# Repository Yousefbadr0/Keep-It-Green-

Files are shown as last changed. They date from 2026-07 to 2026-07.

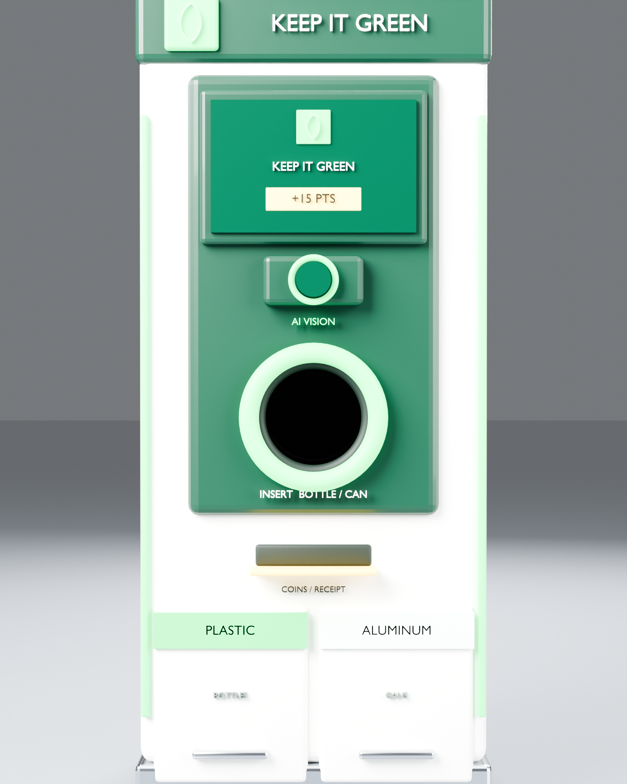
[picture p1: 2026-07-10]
Design/renders/keep_it_green_front.png

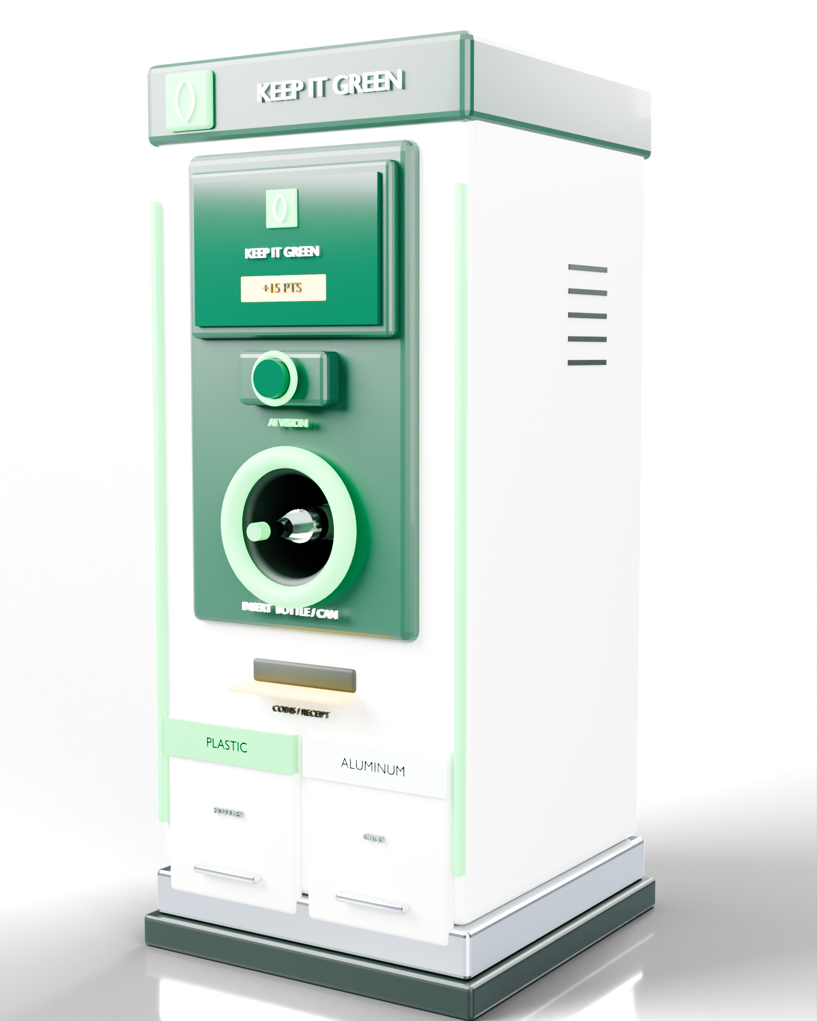
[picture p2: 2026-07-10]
Design/renders/keep_it_green_cutout.png

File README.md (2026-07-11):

# Keep It Green 🌱

An AI-powered smart recycling reward system — graduation project, Menoufia University,
Faculty of Electronic Engineering, Dept. of Computer Science & Engineering (2024–2025).

A user pairs their phone with a recycling machine (ATM-style QR / 6-digit code), inserts
plastic bottles or aluminium cans, a YOLOv8 detector recognizes the material, an Arduino
opens the right compartment, and reward points land on the user's account instantly.

**Live demo:** https://keepitgreen.runasp.net (web app + kiosk + Swagger API docs)

## Repository map

| Folder | What it is | Tech |
|---|---|---|
| `Recycle/` | Backend REST API + web app + kiosk UI (served from `wwwroot/`) | ASP.NET Core (.NET 10), EF Core, SQL Server, JWT |
| `Mobile/` | User + admin mobile app | Flutter (Dart), Material 3 |
| `AI/` | The machine: detector + kiosk driver + Arduino | Python, Ultralytics YOLOv8, pywebview, pyserial |
| `AI/recycling_machine/` | Arduino Nano sketch (2× SG90 servo sorter) | Arduino C++ |
| `Database/` | DDL, backup, ER diagrams, SRS | SQL Server |
| `tests/` | End-to-end API test suites (run against local or live) | Python + requests |
| `Book/` | 105-page graduation book (docx + pdf + assets) | — |
| `Presentation/` | Defense deck + technical deck + scripts | — |
| `Design/`, `Prototype_Boxes/`, `design_handoff_keep_it_green/` | 3D model, renders, brand assets | Blender |
| `Dataset` (archived) | Training data lives on Kaggle; see `AI/keep-it-green_V4.ipynb` | — |
| `_archive/` | Old versions, build scripts, superseded artifacts (safe to delete) | — |

## Architecture (one paragraph)

Five components, one rule: **no client ever touches the database** — everything goes
through the authenticated API. The machine authenticates with an `X-Machine-Key` header;
humans authenticate with JWT (role-based: User / Admin). The machine starts a session →
backend issues a unique pairing code → phone pairs → every accepted item posts a
transaction credited to exactly that user → finishing on either side (phone button or
machine timeout) ends the session on both.

## Running each part

### Backend (serves API + web + kiosk)
```bash
cd Recycle
dotnet run          # http://localhost:5217 — migrations + admin seed run automatically
```
Secrets (connection string, JWT key, machine key, admin seed) come from
`appsettings.json` locally and from the deployed config in production — the committed
file contains **dev values only**. See `DEPLOYMENT.md` for the MonsterASP publish/zip flow.

### Mobile app
```bash
cd Mobile
flutter pub get
flutter run                    # or: flutter build apk --release
```
Points at the live backend by default; override in-app via the Server settings screen.

### Machine (detector + kiosk)
```bash
cd AI
pip install pywebview ultralytics opencv-python pyserial requests "qrcode[pil]"
python machine.py
```
Configuration lives in `AI/machine_config.json` (not committed — copy the example below)
or environment variables `KIG_BACKEND`, `KIG_MACHINE_KEY`, `KIG_MACHINE_ID`:
```json
{ "backend_base": "https://keepitgreen.runasp.net", "machine_key": "<key>",
  "machine_id": 2, "location": "Cairo", "arduino_port": "COM5" }
```
No camera/model installed → it runs in SIMULATE mode (auto-generates items for demos).
Isolated model check: `python test_webcam.py` (watch the `area=` column — ~100% on a
real item means the model failed to localize).

### Arduino sorter
Open `AI/recycling_machine/recycling_machine.ino` in Arduino IDE → Board: *Arduino Nano*
(clones: Processor = *ATmega328P (Old Bootloader)*, CH340 driver) → flash. It self-tests
both gates on power-up. Wiring + power notes: `AI/ARDUINO_WIRING.md`.
Serial protocol 9600 baud: `P` = plastic gate, `A` = aluminium gate, `T` = self-test.

### Tests (23 core + 12 admin + 13 concurrency checks)
```bash
cd tests
set KIG_BASE=https://keepitgreen.runasp.net   # or http://localhost:5217
set KIG_ADMIN_PW=<admin password>             # needed by admin/concurrency suites
python e2e_test.py && python admin_test.py && python concurrency_test.py
```

## The AI model (V4)

YOLOv8s (11.1M params), 2 classes (`plastic_bottle`, `aluminum_can`), trained on
**11,897 real-box images** fused from 4 public detection datasets (Drinking Waste,
Beverage Containers, YOLO Waste Detection, Can/Bottle/Pack) with verified per-dataset
class maps — **no synthetic/full-frame labels**. Held-out test: **mAP@0.5 = 0.928**
(plastic 0.870 / aluminium 0.986), ~69 FPS GPU. Non-recyclables are rejected by a 0.65
confidence gate (open-set rejection). Training notebook: `AI/keep-it-green_V4.ipynb`
(runs on Kaggle, dual T4). Weights: `AI/keep_it_green_best.pt`.

## Deployment

Live on MonsterASP.NET (free tier). Full recipe (publish → trim → forward-slash zip →
app_offline upload) in `DEPLOYMENT.md`.

## Team

Yousef Badr · Eslam Medhat · Ahmed Anwer · Mohanad Ayman · Menna Osama · Shahd El Aswad

## Security & reliability notes

- **Auth:** JWT access tokens (7 days) + rotating refresh tokens (60 days, hash-stored);
  login locks for 5 minutes after 5 failed attempts; machine key compared in constant time.
- **Money path:** redemption runs in a serializable DB transaction (no double-spend).
- **Machine:** failed detection submissions are queued to disk and re-sent (points are
  never lost); the detection loop self-restarts on camera/model errors.
- **Signing:** release APK is signed with `Mobile/android/kig-release.keystore` —
  **back up the keystore + `key.properties` somewhere safe (outside git); losing them
  means you can never update the installed app.**
- Backend builds with **0 warnings / 0 errors**.

## Known technical debt (deliberate, documented)

- CORS is open (`AllowAll`) — safe for a JWT-bearer API (no cookies), tighten if cookies ever appear.
- Old refresh tokens accumulate in the DB — add a periodic cleanup job if usage grows.
- The model's plastic recall (0.76) is the weakest number in the system — label the
  machine's own captures (`AI/prepare_captures.py`) and fine-tune to fix it.

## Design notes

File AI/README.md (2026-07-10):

# Keep It Green — AI / Machine module

Object detection (YOLOv8) **and** the recycling-machine program that runs on the laptop.

## Files

| File | What it is |
|---|---|
| **`machine.py`** | 🖥️ **The machine.** ONE program that runs on the laptop: shows the full-screen ATM kiosk UI (the official design, in a built-in WebView), **and** runs the YOLO model + webcam + Arduino in the same process. |
| `recycling_machine.ino` | Arduino sketch — opens the Plastic/Aluminum compartment on the `P`/`A` serial command. |
| `test_model.py` | Quick model tester (image / folder / video / webcam) — prints detections. No backend. |
| `test_webcam.py` | Minimal live-webcam test. No backend. |
| `keep_it_green_training.ipynb` | Clean training notebook (Kaggle). |
| `keep-it-green.ipynb` | The notebook **after running** (EDA charts, training curves, metrics) — for the presentation. |
| `keep_it_green_best.pt` | Trained YOLOv8 weights (used by `machine.py` + the testers). |
| `best.onnx` | ONNX export (optional). |

## The machine (ATM flow)

`machine.py` is a single program. The UI is the kiosk page the backend serves at `/kiosk/`,
embedded in a borderless full-screen window and **driven directly from Python** (no separate
"bridge" server). The YOLO model runs in Python in the same process.

```
Idle  →  Connected  →  Detected (+pts)  →  Drop it in  →  Summary
(QR + keypad)   (user paired)        (item type, %)     (servo opens)
```

**Starting a session — two ways, both on the idle screen:**
1. **Scan the QR** — the machine creates a session and shows a QR; the user scans it in the app.
2. **Enter a code** — the user taps "Get a code to type" in the app, gets a 6-digit code, and types it on the machine's **on-screen keypad**.

Once paired → the screen shows **Connected — {name}**; each detected item posts a transaction
(awards points), fires the Arduino servo, and animates **Detected → Drop → Connected**.

## Run it

1. **Backend** (serves the kiosk page + API):
   ```bash
   cd ..\Recycle
   dotnet run
   ```
2. **The machine** (this folder):
   ```bash
   pip install pywebview ultralytics opencv-python pyserial requests "qrcode[pil]"
   python machine.py
   ```
   It opens full-screen. Configure the top of `machine.py` if needed:
   - `BACKEND_BASE` (default `http://localhost:5217`)
   - `MACHINE_KEY` (must match `appsettings.json` → `Machine:ApiKey`)
   - `MACHINE_ID`, `ARDUINO_PORT` (`"COM3"` to drive servos, or `None`)
   - `MODEL_PATH`, `CONF_THRESH`, `COOLDOWN_SEC`, `SESSION_IDLE_TIMEOUT`, `POINTS`

> **No camera/model installed?** `machine.py` runs in **SIMULATE** mode and auto-generates items,
> so you can demo the whole QR → pair → items → summary flow without hardware.
> (Uses Windows WebView2, which ships with Windows 10/11.)

## Just testing the model (no backend)

```bash
python test_model.py --source 0        # webcam
python test_model.py --source ./pics   # a folder of images
```

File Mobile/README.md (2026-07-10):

# Keep It Green — Mobile App (Flutter)

The user-facing app, built to the **official design handoff** (`design_handoff_keep_it_green`):
Space Grotesk + Hanken Grotesk, Spring Green `#18C964` / Deep Forest `#0C3B2A` / Sun `#FFC83D`,
springy motion, points always count up. All times are shown in **Cairo time** (`Africa/Cairo`, DST-aware).

## The flow (matches `Keep It Green App.dc.html`)

```
Welcome → Home → "Scan a machine" → Scan QR (or enter code) → PAIR → Live session → Finish
                                   Rewards → Redeem → Redeemed (promo code)
                                   Activity (Today / Earlier, Cairo time)
```

The machine shows a **QR + 6-digit code** (the ATM kiosk). The user **scans it** here (or types it),
which calls `POST /api/Otp/Pair` to open the session — then recycles at the machine while the
**Live session** screen shows items + points counting up.

| Screen | File |
|---|---|
| 01 Welcome / Auth | `welcome_screen.dart`, `login_screen.dart`, `register_screen.dart` |
| 02 Home (points, scan, nearby) | `home_tab.dart` |
| 03 Scan QR (`mobile_scanner`) | `scan_screen.dart` |
| 04 Live session | `live_session_screen.dart` |
| 05 Rewards catalog | `rewards_tab.dart` |
| 06 Redeemed | `redeemed_screen.dart` |
| 07 Activity / History | `history_tab.dart` |
| Profile / logout | `profile_tab.dart` |

Shared: `theme.dart` (brand), `widgets.dart` (LeafToken, PointsPill), `cairo.dart` (Cairo time), `services/api_service.dart`.

## Setup & run

> Requires a recent **Flutter** (3.27+) with Dart 3.

1. **Generate platform folders** (repo ships only `lib/` + `pubspec.yaml`):
   ```bash
   cd "D:\Graduation Project\Mobile"
   flutter create .
   ```

2. **Camera permission for the QR scanner** — one command (patches the generated Android/iOS files):
   ```bash
   powershell -ExecutionPolicy Bypass -File setup_permissions.ps1
   ```
   This adds the Android `CAMERA` permission and the iOS `NSCameraUsageDescription`. It's
   idempotent (safe to re-run). `mobile_scanner` needs Android **minSdk 21+** — Flutter's
   default already satisfies this.

3. **Point at your backend** — `lib/services/api_service.dart`:
   ```dart
   static const String baseUrl = 'http://10.0.2.2:5217';  // Android emulator → host localhost
   ```
   Physical phone: use your PC's LAN IP, e.g. `http://192.168.1.20:5217` (same Wi-Fi).

4. **Run:**
   ```bash
   flutter pub get
   flutter run
   ```
   Start the backend first: `cd ..\Recycle && dotnet run`.

## Notes
- User-role app; admin lives in the web app (`http://localhost:5217`).
- The Scan screen also has **"Enter code manually"** for when the camera isn't ideal.
- Android cleartext HTTP to `10.0.2.2`/LAN works in debug; for release over plain HTTP add a network-security-config (or serve the API over HTTPS).

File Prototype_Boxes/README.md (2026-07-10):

# Keep It Green — prototype collection bins (servo-actuated)

---

## ⭐ CNC / laser cube (the file for the workshop) — `cube_box.py`

A **100 × 100 × 100 mm finger-jointed cube** in **3 mm** material with a
**servo-driven lid**. This is the proof-of-concept the CNC shop cuts.

**Give the shop:** `out/keepitgreen_cube_PLASTIC.dxf` and
`out/keepitgreen_cube_ALUMINUM.dxf` (universal **DXF R12**; he can *Save As DWG*
if he insists — same geometry). Layers: **CUT** (red) = cut through,
**ENGRAVE** (blue) = surface mark / labels. `.svg` twins are for previewing.

**Parts per box (all on one sheet):** BOTTOM, FRONT (label), BACK (cable hole),
RIGHT (SG90 mount), LEFT (pivot), LID, + 2 hinge BRACKETs.

**The lid mechanism (opens/closes with the motor):**
Laser/CNC can't cut a normal pin hinge (the pin would lie flat in the sheet),
so the **lid pivots on the SG90's own shaft**:
1. **SG90** screws into the **RIGHT** wall window (2 × M2), shaft pointing
   inward — this is the hinge axis, along the back-top edge.
2. A screw through the **LEFT** wall (pivot hole) is the coaxial bearing.
3. The two small **BRACKETs** glue under the lid's back corners and ride those
   two pivots; the right one couples to the servo horn.
4. Servo sweeps → lid lifts open ~65° → item drops in → lid closes.
Wiring is unchanged from the AI kiosk: Arduino sends `P` / `A`, the matching
servo sweeps.

**Best-practice details baked in:** finger joints sized exactly to 3 mm, top &
bottom own the corners, **dog-bone overcuts** at inner corners (so it works on a
router *and* a laser), separate CUT/ENGRAVE layers, engraved PLASTIC / ALUMINUM
+ KEEP IT GREEN. Verified by folding the panels into a cube in 3D — it closes
cleanly. Regenerate with `python cube_box.py` (tweak `L`, `T`, `N` at the top).

Preview render: `blender --background --python make_cube_preview.py` (`-- alu`).

---

## (Earlier) 3D-printed bins — `servo_bin.py`

Two small, portable bins that sit under the kiosk. The Arduino reads the YOLO
result, tells the **correct bin's SG90 servo** to lift its top flap, the sorted
item drops in, and the flap closes. Brand-coloured: **Plastic = spring green**,
**Aluminum = mint**, both with a **deep-forest lid**.

## Files

| File | What it is |
|---|---|
| `servo_bin.py` | Parametric Blender model → renders, `.glb`, and **print-ready STL** |
| `cnc_layout.py` | Generates `out/cnc_cut_layout.svg` — flat panels for **CNC/laser wood** |
| `out/bin_body_PLASTIC.stl`, `out/bin_body_ALUMINUM.stl` | The two bin bodies (engraved labels) |
| `out/bin_lid.stl` | The flap lid (print 2×) |
| `out/bin_hinge_pin.stl` | Hinge pin (or use a 3 mm rod / filament) |
| `out/keep_it_green_bins.glb` | Assembled pair **with servo + Nano models** — drop into slides |
| `out/cnc_cut_layout.svg` | 1:1 cut layout (RED = cut, BLUE = etch) |
| `keep_it_green_bins.blend` | Editable source |

## Dimensions (default)

- **Bin:** 90 × 90 × 150 mm internal → ~95 × 95 × 153 mm external (3D-print walls).
  Holds a can / small bottle. For a full 0.5 L bottle, raise `IH` to ~210.
- All parametric at the top of `servo_bin.py`.

## Component "true spaces" (with fit clearance)

| Part | Modelled size | Pocket |
|---|---|---|
| **SG90 servo** | 22.8 × 12.2 × 22.7 mm, tabs @ 28 mm | body window 23.2 × 12.6 mm + 2 × ⌀2.3 screw holes @ 28 mm |
| **Arduino Nano** | 45 × 18 mm board | floor cradle 45.4 × 18.4 mm + USB cut-out 8 × 6 mm |
| **Hinge pin** | ⌀3 mm rod | ⌀3.4 mm ears on body + lid |
| **Cable entry** | — | ⌀7 mm in the back wall |

`CLR = 0.4 mm` clearance is applied to every pocket — tweak for your printer.

## 3D printing (recommended)

- `WALL = 2.5` in `servo_bin.py` (default). Re-run to regenerate STLs.
- Suggested: PLA/PETG, 0.2 mm layers, 3 walls, 15–20 % infill, no supports
  (the lid prints flat; the body prints open-side-up).
- Print: `bin_body_*` ×1 each, `bin_lid` ×2, pin ×2 (or use rod).

## CNC / laser wood

- Set `T` in `cnc_layout.py` (default 6 mm), run `python cnc_layout.py`.
- Butt-jointed + screwed (router-friendly — no sharp inner corners).
- Open `out/cnc_cut_layout.svg` in LightBurn/Inkscape/your CAM tool.

## Assembly & wiring

1. Screw the **SG90** into the right-wall window (2 × M2 self-tappers).
2. Drop the **Nano** into the floor cradle; USB faces the front slot.
3. Fit the **lid** with the **pin** through the rear ears; screw the servo
   horn to the lid's lever tab so rotating the servo lifts the flap.
4. Wire: servo signal → an Arduino D-pin (e.g. D9 / D10), servo V+/GND →
   5 V/GND; route the servo lead down to the Nano, power in via the rear hole.
5. Arduino reads `P` / `A` over serial (per the AI kiosk) and sweeps the
   matching servo open→pause→closed.

## Regenerate

```bash
"C:\Program Files\Blender Foundation\Blender 4.3\blender.exe" --background --python servo_bin.py
python cnc_layout.py
```
Add `-- quick` for a fast preview render, `-- nodummies` to hide the servo/Nano models.

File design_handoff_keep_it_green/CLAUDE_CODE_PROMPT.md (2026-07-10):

# Claude Code — copy-paste prompts

Unzip this folder into (or next to) your repo first. Each prompt assumes Claude Code can read
`brand/tokens.json`, `brand/tokens.css`, `brand/flutter_theme.dart`, and the design references:
`Keep It Green Brand.dc.html` (brand board), `Keep It Green App.dc.html` (7 mobile screens),
and `Keep It Green Machine.dc.html` (5 kiosk states). Open them in a browser to see the exact look.

---

## 0. Shared preface (paste at the top of any prompt)

> You are building **Keep It Green**, a smart-recycling rewards product. Before writing code, read
> `design_handoff_keep_it_green/brand/tokens.json` and open `Keep It Green Brand.dc.html` to absorb the
> brand: Spring Green `#18C964` (primary), Deep Forest `#0C3B2A` (dark surfaces), Sun `#FFC83D` (points/rewards),
> Paper `#F6F7F1`, Charcoal `#13201A`. Fonts: **Space Grotesk** (headings/numbers/labels) + **Hanken Grotesk** (body).
> Motion is springy and rewarding — overshoot on actions, points always count up. Match these exactly.

---

## 1. Mobile app (Flutter)

> [Shared preface]
>
> Scaffold a **Flutter** app (Material 3) using `design_handoff_keep_it_green/brand/flutter_theme.dart` as the theme.
> Add deps: `flutter_riverpod`, `go_router`, `dio`, `mobile_scanner`, `flutter_secure_storage`, `google_fonts`.
> **Match `Keep It Green App.dc.html` screen-for-screen** — it has all 7 designs (Welcome, Home, Scan, Live
> session, Rewards, Redeemed, History). Build them with the Keep It Green look:
> 1. **Welcome / Auth** (sign up / log in) — JWT stored in secure storage. Forest background, leaf token.
> 2. **Home** — points balance card (Forest card, Sun number), big "Scan a machine" button, nearby machines.
> 3. **Scan** — full-screen `mobile_scanner` with the green corner-bracket frame to read a machine QR.
> 4. **Live session** — shows each detected item (Plastic / Aluminum / Other) with a "+15 pts" badge and
>    **animates the total counting up** on accept; lists items dropped this session.
> 5. **Rewards** — vendor promo grid with points-cost pills; tap a reward to **Redeem** (deducts points).
> 6. **Redeemed** — success screen revealing the promo code in a dashed box, shows new balance.
> 7. **History** — transactions and redemptions grouped by Today / This week.
>
> Use a `dio` API client pointing to a configurable base URL for the .NET backend. Keep widgets reusable
> (PointsBadge, MachineCard, RewardTile). Use the leaf app icon from `assets/`.

---

## 2. Machine kiosk (Python + FastAPI + HTML)

> [Shared preface]
>
> Build the **recycling-machine kiosk UI** that runs on the laptop. Use **FastAPI** to serve a single
> fullscreen HTML/CSS/JS page and a **WebSocket** that the detection loop pushes events to. **Match
> `Keep It Green Machine.dc.html`** — it has all 5 states: **Idle/Welcome** ("Ready when you are" + QR) →
> **Session active** (waiting for item, green target frame) → **Detected** (item type + confidence + "+15
> points", springy reveal) → **Drop it in** (the correct compartment highlighted OPEN) → **Session summary**
> (items recycled + points earned, Spring Green screen).
>
> Wire it to the hardware pipeline:
> - YOLO inference with **Ultralytics** + **OpenCV** webcam capture; classes Plastic Bottle / Aluminum Can / Other.
> - On accept above a confidence threshold, POST the transaction to the .NET backend, then send a serial
>   command to Arduino via **pyserial**: `P` plastic, `A` aluminum, `O` other.
> - Push every state change to the kiosk page over WebSocket so the UI animates in real time.
> Also give me a minimal **Arduino C++ sketch** that reads the serial char and drives Servo 1 (plastic) or Servo 2 (aluminum).
> Launch instructions: run Chromium in `--kiosk` pointed at the local FastAPI URL.

---

## 3. Website (Next.js + Tailwind)

> [Shared preface]
>
> Build a **Next.js (App Router) + Tailwind** site. Map `brand/tokens.json` colors into `tailwind.config`
> (spring, forest, sun, mint, paper, charcoal) and load Space Grotesk + Hanken Grotesk via `next/font/google`.
> Deliver: (a) a **marketing landing page** (hero with the leaf lockup, how-it-works: scan → drop → earn → redeem,
> machine locations, app download CTAs) in the Keep It Green style; and (b) a **vendor portal** (auth, create/manage
> promo codes, view redemptions) that talks to the .NET API. Reuse the leaf SVGs from `assets/`.

---

## 4. Backend (ASP.NET Core) — optional, if not started

> Build an **ASP.NET Core (.NET 8) Web API** with **EF Core + SQL Server** and **JWT** auth. Entities:
> Users, Machines, Sessions, Transactions, Vendors, PromoCodes, Redemptions (see the project spec). Endpoints
> for auth, session start/stop, transaction logging (store image path only), rewards listing, and redemption.
> Add **SignalR** for real-time machine ↔ backend events. Provide EF migrations and seed data.

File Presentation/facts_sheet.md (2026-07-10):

# Keep It Green — Presentation Facts Sheet (cited)

> Source of truth for every number in the deck. Each fact notes **[USE]** = where it lands in the pitch.
> Compiled July 2026. Verify a couple of headline figures the night before (some are model estimates).

## 1. The global problem (Act I — Problem)
- **1,000,000 plastic bottles are bought every minute worldwide** (~500 billion/year). [USE: opening hook] — The National / EcoWatch, 2024.
- **Only ~9% of plastic is recycled globally**; the rest is landfilled, burned, or leaks into nature. [USE: the gap] — The National, 2024.
- **PET bottle** global recycling rate **~47%**; **aluminum can ~75%** (most-recycled beverage container). [USE: why our two classes] — Eunomia via Packaging Dive, 2023.
- Aluminum is **infinitely recyclable** and recycling it uses **95% less energy** than virgin production. [USE: environmental payoff] — Aluminum Association.

## 2. Why it matters in Egypt (Act I — local stakes; Act IV — market)
- Egypt generates **~100 million tonnes of waste/year** (~**80,000 tons/day**). [USE: scale] — Waste Management in Egypt (Wikipedia).
- National MSW **recycling rate: 10% (2018) → 37% (2024)**, government **target 60% by 2027**. [USE: momentum + policy tailwind] — Egyptian Streets, 2025.
- **~2.5 million tons of plastic waste/year** (10–14% of total waste). [USE: plastic-specific] — UNIDO / Egyptian Streets.
- Egypt plastic-recycling market: **$380M (2024) → $474M (2030)**. [USE: market growing] — CSR Egypt / GlobeNewswire, 2025.

## 3. The insight: incentives work (Act I→II — the thesis)
Where a reward exists, people return containers. Deposit-Return Schemes (DRS) powered by reverse vending:
- **Germany: >98% container return** (98.4%), ~**135,000 return points**, €0.25/item, since 2003. [USE: proof] — TOMRA.
- **Norway: 97% plastic-bottle recycling**; **3,500 reverse vending machines collect 93%** of packaging; since 1996. [USE: proof + RVM centrality] — TOMRA.
- **Contrast:** no-incentive systems lag badly (global plastic 9%, Egypt 37%). [USE: the "aha" — Egypt has no reward layer yet]

## 4. Market opportunity (Act IV — Market / TAM-SAM-SOM)
- **Reverse Vending Machine market: ~$0.86B–$1.2B (2024) → ~$2.0B by 2030**, CAGR **~7.5–8.5%**. [USE: TAM] — Strategic Market Research / Transparency Market Research.
- Egypt digital readiness (perfect for a mobile-first reward app):
  - **Population 113.6M, median age 24.3** (very young). [USE: SAM/adoption] — DataReportal 2024.
  - **Internet penetration 72.2% (82M users)**; **96% access via mobile**; **110.5M mobile connections (97.3%)**. [USE: mobile-first fit] — DataReportal 2024.
  - **96.7% of youth (18–29) use mobile phones**. [USE: target user] — CAPMAS via Egypt Today.

## 5. Unit economics / business model inputs (Act IV — Business model)
- Recovered-material value in the bin: **Aluminum $1,338/ton**, **PET $215/ton**, glass −$23/ton. [USE: why we reward Aluminum > Plastic, and the material-resale revenue line] — Aluminum Association.
- Our points map to material value: **Plastic = 10 pts, Aluminum = 15 pts** (aluminum worth ~6× PET per ton → higher reward is economically rational).
- Revenue streams to pitch: (1) **vendor/brand partnerships** (promo redemptions = paid placement), (2) **recovered-material resale**, (3) **machine sponsorship / branded wraps**, (4) **CSR/ESG contracts** with corporates & municipalities, (5) **anonymized recycling data**.

## 6. Competition (Act IV — Competition)
- **TOMRA** (Norway) — global RVM leader, ~80% share of DRS machines; hardware-heavy, deposit-law dependent.
- **Bower** (Sweden) — app that rewards recycling via barcode scanning; no detection hardware.
- **Local/informal** — Egypt's Zabaleen collectors, Bekia, Recyclobekia (buy-back apps).
- **Our wedge:** AI camera (no deposit law or barcodes needed) + mobile rewards + ATM-style pairing, built for an emerging market without a national DRS.

## 7. What we built (Act III — Traction) — internal facts, no citation needed
- **4 integrated platforms:** YOLO AI detection (Plastic/Aluminum) · .NET + SQL backend · Flutter mobile app · web dashboard · Arduino-driven machine.
- **ATM-style pairing:** machine shows QR/6-digit code; phone scans or types to pair; live session.
- **Working & tested:** end-to-end automated tests — **23/23 core + 12/12 admin passing**; role-based access (User/Admin), machine-key auth, JWT.
- **Detection confidence buffer** (item confirmed over ~1.2s) to avoid misfires; anti-double-count.
- Cairo-time throughout; installable Android APK + web app + kiosk.

## 8. Team (Team slide)
- **Yousef Badr** — Team Leader · AI & Hardware (system architect; built the end-to-end project)
- **Eslam Medhat** — AI
- **Ahmed Anwer** — AI
- **Mohanad Ayman** — Mobile App
- **Menna Osama** — Front End
- **Shahd El Aswad** — Back End

## 9. Visual & 3D assets (for the deck)
- **3D model (machine):** `Design/keep_it_green_machine.glb` (native-PowerPoint 3D → live Turntable animation), also `.obj/.mtl/.fbx`. Materials already brand-colored (green cap, off-white body).
- **3D model (bins):** `Prototype_Boxes/out/keep_it_green_bins.glb` (+ STLs for the physical CNC/print bins — proof of hardware).
- **Existing renders (stills):** `Design/renders/keep_it_green_hero.png`, `keep_it_green_front.png`, `keep_it_green_cutout.png`; `Prototype_Boxes/renders/keep_it_green_bins.png`, `keep_it_green_bins_interior.png`.
- **Brand:** `design_handoff_keep_it_green/assets/` (logo lockup, leaf logos, app icons); tokens — Spring #18C964, Deep Forest #0C3B2A, Sun #FFC83D, Paper #F6F7F1; fonts Space Grotesk (display) + Hanken Grotesk (body).
- **Product screenshots:** login, kiosk choice/summary, mobile welcome (captured); can capture more.
- **Architecture diagram:** already designed (4-platform ATM flow).

---
### Source links
- https://www.thenationalnews.com/health/2024/09/25/one-million-bottles-of-water-bought-every-minute-around-the-world/
- https://www.ecowatch.com/plastic-bottle-crisis-2450299465.html
- https://www.packagingdive.com/news/aluminum-beverage-can-glass-pet-recycling-rates-eunomia-cop30/805222/
- https://www.aluminum.org/Recycling
- https://en.wikipedia.org/wiki/Waste_management_in_Egypt
- https://egyptianstreets.com/2025/08/11/egypt-accelerates-waste-reforms-and-targets-60-percent-recycling-by-2027/
- https://www.csregypt.com/en/report-egypt-plastic-recycling-market-expected-to-up-from-380-25-m-in-2024-to-reach-473-96-m-by-2030/
- https://www.tomra.com/reverse-vending/media-center/feature-articles/deposit-return-schemes-europe
- https://www.tomra.com/reverse-vending/media-center/feature-articles/germany-deposit-return-scheme
- https://www.strategicmarketresearch.com/market-report/reverse-vending-machine-market
- https://www.transparencymarketresearch.com/reverse-vending-machine-market.html
- https://datareportal.com/reports/digital-2024-egypt
- https://www.egypttoday.com/Article/1/16931/96-7-of-youth-in-the-age-group-18-29

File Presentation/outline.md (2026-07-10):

# Keep It Green — Defense Deck Outline (24 slides · ~25–30 min · hybrid)

Legend: **MSG** = the one thing they remember · **VISUAL** = art/asset · **DATA** = cited number (see facts_sheet.md) · **TIME** target.
Design system: Deep Forest bg for section/impact slides, Paper bg for content; Spring green accents, Sun for numbers; Space Grotesk headings.

---
## ACT I — THE WHY  (problem & stakes · ~5 min)

**1. Title**
- MSG: A recycling machine that pays you back — built for Egypt.
- VISUAL: logo lockup + `keep_it_green_hero.png`; tagline "Recycling that rewards you." Team + university + date.
- TIME: 0:30

**2. The scale of the problem**
- MSG: We're buying plastic faster than we can ever recycle it.
- DATA: **1,000,000 plastic bottles bought every minute** (~500B/yr); **only ~9% recycled**.
- VISUAL: one giant number on Forest bg; small bottle-grid motif.
- TIME: 1:30

**3. Egypt is drowning in it**
- MSG: The crisis is on our doorstep, and it's mostly unrecycled.
- DATA: **~100M tonnes waste/yr** (~80k tons/day); plastic recycling **only 37%**; 2.5M tons plastic/yr.
- VISUAL: Egypt map/silhouette + stat callouts.
- TIME: 1:30

**4. Why people don't recycle**
- MSG: It's not apathy — there's no reward, no convenience, no feedback.
- VISUAL: 3 friction icons (no incentive · inconvenient · invisible impact).
- TIME: 1:00

## ACT II — THE WHAT  (solution & product · ~7 min)

**5. The proven fix: reward it**
- MSG: Where returning a bottle pays, people recycle almost everything.
- DATA: **Germany 98%**, **Norway 97%** container return — via reverse vending (Norway: 3,500 RVMs collect 93%).
- VISUAL: 98% / 97% vs Egypt 37% bar comparison.
- TIME: 1:30

**6. Introducing Keep It Green** ★ 3D
- MSG: AI-powered reverse vending + instant mobile rewards — no deposit law required.
- VISUAL: **live .glb turntable** of the machine (fallback `hero.png`); one-line definition.
- TIME: 1:30

**7. How it works (the ATM flow)**
- MSG: Scan, drop, earn — in under a minute.
- VISUAL: 3-step flow: (1) machine shows QR/code → phone pairs, (2) drop item → AI detects, (3) points land + redeem. Reuse the system-flow diagram.
- TIME: 1:30

**8. Watch it sort** ★ 3D
- MSG: The camera decides, the right bin opens.
- VISUAL: bins `.glb`/`keep_it_green_bins_interior.png`; Plastic→bin A, Aluminum→bin B; servo callout.
- TIME: 1:00

**9. The mobile app**
- MSG: The reward layer lives in your pocket.
- VISUAL: 3–4 app screenshots (welcome · scan/pair · points/home · rewards). Cairo-time, points, redeem.
- TIME: 1:00

**10. The machine screen (kiosk)**
- MSG: A friendly ATM-style flow anyone can use.
- VISUAL: kiosk screenshots (idle QR + keypad · detected · add-another/finish · summary).
- TIME: 0:30

## ACT III — THE HOW  (technical depth · ~7 min)

**11. The AI brain**
- MSG: Real-time computer vision classifies each item with a confidence buffer to avoid mistakes.
- DATA: YOLO detector, 2 classes (Plastic/Aluminum), **~1.2 s stability confirmation**, trained on our dataset (show sample images).
- VISUAL: detection frame with box + confidence; dataset montage.
- TIME: 1:45

**12. System architecture**
- MSG: Five components, one clean data flow.
- VISUAL: architecture diagram (AI machine · .NET+SQL backend · Flutter app · web dashboard · Arduino). X-Machine-Key + JWT labeled.
- TIME: 1:30

**13. Security & trust**
- MSG: Every action is authenticated and role-scoped.
- VISUAL: JWT + roles (User/Admin) · machine-key header · OTP session pairing (nullable until paired).
- TIME: 1:00

**14. Tech stack (and why)**
- MSG: Production-grade, not a prototype.
- VISUAL: stack logos grid — .NET/EF/SQL Server · Flutter/Dart · Ultralytics YOLO/OpenCV · Arduino/servo · PWA.
- TIME: 1:00

**15. Built & tested** (traction proof)
- MSG: It's not slides — it's a working system.
- DATA: 4 platforms live; **23/23 core + 12/12 admin automated tests passing**; installable APK + web + kiosk.
- VISUAL: green test checklist; "scan to try the app" QR.
- TIME: 1:15

## ACT IV — THE BUSINESS  (market & model · ~6 min)

**16. Market opportunity**
- MSG: A proven global market, still absent in Egypt.
- DATA: RVM market **~$1B (2024) → ~$2B by 2030**, CAGR ~8%; Egypt plastic-recycling **$380M→$474M**.
- VISUAL: TAM/SAM/SOM funnel + market growth chart.
- TIME: 1:30

**17. Why Egypt, why now**
- MSG: A young, mobile-first population and a government tailwind.
- DATA: **113M people, median age 24**, **97% mobile connections**, youth 96.7% phone use; national **60% recycling target by 2027**.
- VISUAL: 3 demographic stat cards + policy note.
- TIME: 1:00

**18. Business model**
- MSG: We earn while we clean up.
- DATA: 5 streams — vendor/brand redemptions · **recovered-material resale (Aluminum $1,338/ton vs PET $215)** · machine sponsorship · CSR/ESG contracts · anonymized data. Points map to material value (Al 15 > Plastic 10).
- VISUAL: revenue-streams diagram + unit-economics mini table.
- TIME: 1:30

**19. Competition & our edge**
- MSG: Global players need deposit laws and barcodes — we don't.
- VISUAL: 2×2 or comparison table: TOMRA · Bower · local buy-back vs **Keep It Green** (AI detection · mobile rewards · no-DRS · emerging-market fit).
- TIME: 1:00

**20. Go-to-market**
- MSG: Start where footfall + sustainability budgets meet.
- VISUAL: phased rollout — Pilot (universities, malls, corporate campuses) → City clusters → National; partner logos placeholder.
- TIME: 1:00

## ACT V — THE CLOSE  (impact & ask · ~4 min)

**21. Impact**
- MSG: Every can counts — environmentally and socially.
- DATA: aluminum recycling uses **95% less energy**; material recovered → CO2 avoided; rewards + green jobs.
- VISUAL: before/after or impact stat trio (Forest bg).
- TIME: 1:00

**22. Roadmap**
- MSG: Clear path from campus pilot to national network.
- VISUAL: timeline — now (working system) → more materials/machines → loyalty partners → data platform.
- TIME: 1:00

**23. Team**
- MSG: A full-stack team that shipped a real product.
- VISUAL: 6 cards — Yousef Badr (Lead · AI & Hardware), Eslam Medhat (AI), Ahmed Anwer (AI), Mohanad Ayman (Mobile), Menna Osama (Front End), Shahd El Aswad (Back End).
- TIME: 0:45

**24. Vision + Ask**
- MSG: A greener Egypt, one bottle at a time — here's how you can help.
- VISUAL: Forest bg, logo, the ask (pilot site / funding / mentorship), "Thank you", demo QR.
- TIME: 1:00

---
### Build notes
- ~24 content slides; each ≤ ~20 words on screen — detail goes in speaker notes.
- 3D turntable on slides 6 (& optionally 8) via native `.glb`; `hero.png` poster fallback.
- Charts to generate: 98/97/37 bar (S5), market growth (S16), TAM/SAM/SOM (S16), revenue streams (S18), competition table (S19).
- Reusable diagram: system/ATM flow (S7, S12).

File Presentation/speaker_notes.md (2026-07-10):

# Keep It Green — Speaker Notes & Q&A (≈25–30 min)

**Flow:** Problem (5) → Solution & product (7) → Technology (7) → Business (6) → Close (4).
**Golden rule:** one message per slide, say the number, then the "so what." Don't read the slide.

---
## ACT I — THE WHY (≈5 min)

**1 · Title (0:30)** — "Good morning. We're Keep It Green. We built a recycling machine that pays you back — AI-powered reverse vending, made for Egypt." Introduce the team in one line. Set energy.

**2 · The problem (1:30)** — "Every minute, the world buys a million plastic bottles — half a trillion a year. And only about 9% is ever recycled." Let the number land. "This isn't a habit problem — it's a system problem."

**3 · Egypt (1:30)** — "Here at home it's stark: 100 million tonnes of waste a year, and plastic recycling still sits around 37%." Then the hopeful pivot: "The government wants 60% by 2027 — the pressure and the policy are both moving."

**4 · Why people don't recycle (1:00)** — "Ask anyone why they don't recycle. It's never 'I don't care.' It's: there's no reward, it's inconvenient, and you never see your impact. Fix those three and behavior changes."

## ACT II — THE WHAT (≈7 min)

**5 · Rewards work (1:30)** — "We know this works. Germany returns 98% of its containers. Norway, 97%. The difference isn't culture — it's a reward, delivered through reverse vending machines. Egypt simply has no reward layer yet. That gap is our opportunity."

**6 · Keep It Green + 3D (1:30)** — Play the 3D tour. "This is our machine. You place a bottle or can, the camera identifies it, and points hit your phone instantly — no deposit law, no barcodes, no staff." Let the rotation/zoom do the talking.

**7 · How it works (1:30)** — Walk the three steps. "Pair like an ATM — scan a QR or type a 6-digit code. Drop the item; the AI confirms it. Points land and you redeem them in the app. Under a minute, start to finish."

**8 · Watch it sort (1:00)** — "Once the camera decides, an Arduino opens the correct compartment — Plastic to one bin, Aluminum to the other. This is a working hardware prototype, not a render."

**9 · Mobile app (1:00)** — "The reward layer lives in the app: scan and pair, watch points land in Cairo time, redeem for vendor rewards — and the promo code is only revealed after you redeem."

**10 · Kiosk (0:30)** — "The machine screen is deliberately ATM-simple. Place an item… and finish with a clear reward summary — points earned and your new total."

## ACT III — THE HOW (≈7 min)

**11 · AI (1:45)** — "The brain is a YOLO computer-vision model that classifies each item live. Two classes — plastic and aluminum. And a confidence buffer: the item has to stay confidently detected for about 1.2 seconds before it counts, so a glance or a wrong read never triggers a reward." Mention the dataset.

**12 · Architecture (1:30)** — "Five components, one flow. The AI machine, a .NET backend on SQL Server, the Flutter app, the web dashboard, and the Arduino hardware. Crucially, nothing touches the database directly — every request is authenticated through the backend."

**13 · Security (1:00)** — "Every action is authenticated and role-scoped. Users get JWTs; admins and users are separated; machines carry a secret key; and a detection is only ever credited to the user paired to that live session."

**14 · Tech stack (1:00)** — "This is a production-grade stack, not a class prototype." Name each layer briefly and why it was chosen.

**15 · Built & tested (1:15)** — "And it's real. All five components run. We wrote automated end-to-end tests — 23 of 23 on the core flow, 12 of 12 on admin — and they pass: register, pair, detect, earn, redeem, all verified. There's an installable APK, a web app, and the kiosk."

## ACT IV — THE BUSINESS (≈6 min)

**16 · Market (1:30)** — "The reverse-vending market is about a billion dollars today, roughly two by 2030. Egypt's recycling market is growing too. Our beachhead is Cairo — universities, malls, and corporate campuses."

**17 · Why Egypt now (1:00)** — "The timing is ideal: 113 million people, median age 24, 97% on mobile. A mobile-first reward app fits perfectly — and the 60% national target pushes with us."

**18 · Business model (1:30)** — "We make money while we clean up: vendors pay for the promos users redeem, we resell recovered material, plus sponsorship, ESG contracts, and data. And notice — aluminum is worth $1,338 a ton versus $215 for PET. That's exactly why we reward aluminum more. The points mirror real value."

**19 · Competition (1:00)** — "The global leaders need deposit laws and barcodes. We need neither — our camera reads the item directly. That makes us the fit for an emerging market that has no national deposit scheme."

**20 · Go-to-market (1:00)** — "We start where footfall meets sustainability budgets — pilot on campuses and in malls, densify into city clusters, then scale with municipality and ESG contracts."

## ACT V — THE CLOSE (≈4 min)

**21 · Impact (1:00)** — "The payoff is real: recycling aluminum uses 95% less energy than making it new. Material goes back into the economy instead of the Nile, and the machines create rewards and green jobs."

**22 · Roadmap (1:00)** — "From here: more materials, more machines, brand partners, and ultimately a recycling-data platform for cities."

**23 · Team (0:45)** — Introduce each member and their role. Keep it warm and quick.

**24 · Vision + Ask (1:00)** — "A greener Egypt, one bottle at a time. We're looking for a pilot site, funding, and mentorship to get there. Thank you — we'd love your questions."

---
## Q&A — likely questions & strong answers

**How accurate is the AI, and what about items it hasn't seen?** Two-class model with a confidence threshold plus a 1.2-second stability buffer, so low-confidence or unfamiliar items are simply rejected rather than mis-rewarded. Captured images feed continuous retraining.

**What stops fraud — fake Q', empty bottles, gaming the points?** Detections are only credited to the paired session; the machine authenticates with a secret key; and a cooldown plus "item must clear before the next counts" prevents double-counting. Weight/volume sensing is on the roadmap.

**Why not just use barcodes like Bower?** Barcodes require a clean, scannable label and a product database. Our camera classifies the material directly — it works on crushed, label-less, or unfamiliar containers, which is the real-world case in Egypt.

**How is this different from TOMRA?** TOMRA depends on national deposit laws and expensive hardware. We reward through the app without a deposit scheme, at a fraction of the cost — designed for markets that don't have DRS.

**What's the unit economics / how do you make money?** Vendor-funded rewards and recovered-material resale (aluminum ~$1,338/ton) are the core; sponsorship, ESG contracts, and data add to it. Aluminum-heavy streams are cash-positive on material alone.

**Why should a vendor pay you?** Measurable, sustainability-aligned footfall and redemptions — a green loyalty channel to a young, mobile audience, with data to prove ROI.

**Is the hardware real or simulated?** Real: Arduino-driven servos open the correct bin, and there's a working machine program running the camera and UI. We also have 3D-printable/CNC bin parts.

**How do you scale manufacturing and placement?** Start with a few pilot units on campuses/malls, standardize the enclosure (we have the CAD), and grow placement through property and ESG partnerships.

**What about connectivity/offline?** The machine talks to the backend over the network; sessions are short and idempotent. Offline queueing of transactions is a straightforward addition.

**Security of user data?** JWT auth, role separation, no direct DB access, and no sensitive personal data stored beyond account basics. Times are handled in Cairo time; secrets are rotated before deployment.

**What's the biggest risk, honestly?** Placement economics and vendor supply at scale. We de-risk with a campus pilot to prove redemption rates before committing to hardware volume.

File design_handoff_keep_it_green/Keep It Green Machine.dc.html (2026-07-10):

01 · Idle — Welcome

Ready when you are

Scan the QR with your Keep It Green app to start

Riverside Park · Online

02 · Session active — place item

Connected — Lina

60 pts this session

Place an item in front of the camera

Plastic bottles and aluminum cans earn points

03 · Item detected

✓

Plastic bottle

96% confident

+15 points

04 · Drop it in (door opens)

Drop it in the green bin

→

Plastic

OPEN

Aluminum

closed

Compartment opens automatically · servo 1

05 · Session summary

Nice work, Lina!

4

items recycled

+60

points earned

Check your app for the total

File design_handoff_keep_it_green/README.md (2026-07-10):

# Handoff: Keep It Green — Brand & Surfaces

## Overview
**Keep It Green** is a smart-recycling reward system: users scan a recycling machine, drop bottles/cans, an on-device YOLO model classifies the item, the correct compartment opens, and the user earns points redeemable for vendor promo codes. This package contains the **brand identity** and the **recommended tech stack** for each surface (mobile app, machine kiosk, website, backend), ready to hand to Claude Code.

## About the design files
The HTML file in this bundle (`Keep It Green Brand.dc.html`) is a **design reference** — a high-fidelity prototype of the brand system, not production code to ship. The task is to **rebuild these designs in each target environment** (Flutter, a web kiosk, Next.js) using that environment's idiomatic patterns, pulling exact values from the tokens in `/brand`.

## Fidelity
**High-fidelity.** Colors, typography, radii, and motion are final. Match them exactly.

---

## Screens / Views
The full screen-by-screen designs are in the HTML references (open in a browser):
- **`Keep It Green App.dc.html`** — 7 mobile screens: 01 Welcome/Auth · 02 Home · 03 Scan QR · 04 Live session · 05 Rewards · 06 Redeemed · 07 History.
- **`Keep It Green Machine.dc.html`** — 5 kiosk states: 01 Idle/Welcome · 02 Session active (place item) · 03 Item detected · 04 Drop it in (compartment opens) · 05 Session summary.

## Brand system (recreate exactly)

### Logo
The mark is a **single leaf inside a rounded "token"** — the same shape points live in, so the mark reads as *recycling = reward*. Leaf veins double as motion lines.
- `assets/logo-app-icon.svg` — green token + white leaf (app icon / favicon)
- `assets/app-icon-1024.png`, `-512.png`, `-192.png` — rasterized icons (iOS / Android / web)
- `assets/logo-leaf-green.svg` — leaf only, for light backgrounds
- `assets/logo-leaf-white.svg` — leaf only, for dark backgrounds
- `assets/logo-lockup-horizontal.svg` — mark + "Keep It **Green**" wordmark (needs Space Grotesk to render text; outline or recreate in code for production)
- **Monogram:** `KIG` set in Space Grotesk Bold
- **Clear space:** ≥ 0.5× the token height on all sides. **Min size:** 32px.

### Color  (also in `brand/tokens.css` / `tokens.json`)
- Spring Green `#18C964` — primary: mark, CTAs, accents
- Deep Forest `#0C3B2A` — dark surfaces: hero, machine panels
- Sun `#FFC83D` — reward accent: points, badges, coins
- Mint `#DCF1E2` — tint surface
- Paper `#F6F7F1` — app / page background
- Charcoal `#13201A` — text · Muted `#6B7A72` — secondary text

### Typography
- **Space Grotesk** (400/500/700) — headings, numbers, UI labels. Labels are uppercase, letter-spacing `.14em`.
- **Hanken Grotesk** (400/500/600/700) — body copy, line-height ~1.7.
- Scale (px): Display 52 · H1 32 · Subtitle 22 · Body 17 · Label 13.

### Motion
Springy and rewarding. Actions land with a small overshoot (`cubic-bezier(.2,.8,.3,1.4)`); **points always count up**; the leaf gently grows. Never stiff, never slow. Keep durations ~0.6–0.9s.

---

## Recommended stack (per surface)

These align with the team's existing plan (3 AI, 2 .NET, 1 Flutter).

### 1. Mobile app — **Flutter**
- Flutter + Material 3 (`useMaterial3: true`), theme in `brand/flutter_theme.dart`
- `google_fonts` (Space Grotesk + Hanken Grotesk)
- State: **Riverpod** (`flutter_riverpod`)
- Routing: `go_router`
- Networking: `dio` → the .NET API
- QR scanning: `mobile_scanner`
- JWT storage: `flutter_secure_storage`
- Core screens: Onboarding/Auth → Home (points balance) → **Scan QR** → Live session (detected item + points count-up) → Rewards catalog → Redeem → History.

### 2. Machine kiosk — **Python web kiosk** (reuses these HTML designs almost 1:1)
- The laptop already runs Python for YOLO, so serve the UI from the same process:
  - **FastAPI** serving a fullscreen HTML/CSS/JS page; **WebSocket** pushes live events (detected type, confidence, points, door state) to the screen.
  - Run **Chromium in `--kiosk`** fullscreen on the laptop.
- AI: **Ultralytics YOLO (v8/11)** + **OpenCV** capture; classes: Plastic Bottle / Aluminum Can / Other.
- Hardware: **pyserial** → Arduino. Protocol: send `P` (plastic), `A` (aluminum), `O` (other). Arduino C++ sketch reads serial and drives the matching servo.
- *Alternative:* Flutter **desktop** (shares code with the app) if you'd rather not run a browser.

### 3. Website — **Next.js (App Router) + Tailwind**
- Marketing/landing + a **vendor portal** (manage promo codes, view redemptions).
- Map `tokens.json` into `tailwind.config` (`spring`, `forest`, `sun`, …); load both fonts via `next/font/google`.

### 4. Backend — **ASP.NET Core Web API** (already chosen)
- .NET 8 Web API + **EF Core** + **SQL Server**, **JWT** auth (`Microsoft.AspNetCore.Authentication.JwtBearer`).
- Images: store files in blob/local storage, **only the path in DB** (as planned).
- Add **SignalR** for real-time machine ↔ backend session/transaction events.
- Tables per the project spec: Users, Machines, Sessions, Transactions, Vendors, PromoCodes, Redemptions.

---

## How to hand this to Claude Code
1. **Download this folder** (zip) and unzip it into — or beside — your repo.
2. Open the repo in Claude Code.
3. Copy a prompt from **`CLAUDE_CODE_PROMPT.md`** (one each for app / kiosk / website), paste it into Claude Code, and point it at this folder. Each prompt tells it to read `/brand/tokens.*` and the brand board for exact values.
4. Build one surface at a time. Start with the **mobile app** or **machine kiosk** — they're the demo-critical surfaces for a grad project.

## Files in this bundle
- `Keep It Green Brand.dc.html` — the brand board prototype (open in a browser)
- `Keep It Green App.dc.html` — 7 mobile app screens (Welcome, Home, Scan, Live session, Rewards, Redeemed, History)
- `Keep It Green Machine.dc.html` — 5 machine kiosk states (Idle, Waiting, Detected, Drop-it-in, Summary)
- `assets/` — logo SVGs + PNG app icons + favicon
- `brand/tokens.css`, `brand/tokens.json` — design tokens (source of truth)
- `brand/flutter_theme.dart` — ready-made Flutter ThemeData
- `CLAUDE_CODE_PROMPT.md` — copy-paste prompts for Claude Code

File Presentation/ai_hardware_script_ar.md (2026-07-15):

# سكريبت جزء الـ AI والهاردوير — (سلايدات ١٦–٢٣) 🎤

> المدة المتوقعة: ٥–٦ دقايق. الأرقام كلها حقيقية من الموديل V4 ومن السلايدات.
> نصيحة عامة: احكي قصة، متقراش أرقام. القصة: "جربنا وغلطنا ٣ مرات، وفهمنا ليه، والنسخة الرابعة نجحت."

---

## 🟢 سلايد ١٦ — AI · FRAMING (حوالي ٤٠ ثانية)

إحنا محتاجين الماكينة تعمل حاجة واحدة بس، بس تعملها صح:
تعرف **الإزازة البلاستيك** و**الكانز الألومنيوم**… وترفض أي حاجة تانية.

في الداتا اللي لقيناها، لو جمعنا كل حاجة "تانية" — زجاج وورق وأكواب وزبالة — هنلاقي حوالي **٤٤ ألف صورة**، مقابل كام ألف بس للبلاستيك والألومنيوم. لو دربنا كلاس اسمه "Other" بالحجم ده، هو اللي هيسيطر على التدريب وهيبوّظ كل حاجة.

فقرارنا كان مختلف: نـدرّب الموديل على **كلاسين بس**، ونستخدم **الثقة بتاعة الموديل نفسه كبوابة**:
لو مفيش حاجة عدّت ثقة **٦٥٪** → الحاجة اللي اتحطت مش معروفة، فبنرفضها.
الأسلوب ده اسمه **Open-Set Rejection** — بنرفض المجهول من غير ما نعلّمه أصلاً.

---

## 🟢 سلايد ١٧ — AI · DATASET + قصة الـ ٤ نسخ (حوالي دقيقة و١٥ ثانية)

**ودي أهم حتة في الجزء بتاعي: إحنا معملناش موديل واحد… إحنا عملنا أربع نسخ، وكل نسخة علّمتنا حاجة.**

**النسخة الأولى (V1):** استخدمنا داتاسِتس تصنيف مشهورة — زي TrashNet — ودي صور مفيهاش Bounding Boxes أصلاً، فحوّلناها للـ Detection بإننا خلينا البوكس = **الصورة كلها**. النتيجة على الورق كانت شكلها حلو… بس على الماكينة الحقيقية؟ كارثة. الموديل اتعلم يقول "الصورة كلها بلاستيك" — فكان بيقول في بلاستيك حتى والماكينة **فاضية**.

**النسخة التانية (V2):** زوّدنا داتا وظبطنا الهايبر باراميترز، بس فضلنا على نفس أسلوب البوكس الكامل — حوالي **٧٤٪** من البوكسات كانت full-frame — وكمان كان في عدم توازن: بلاستيك أكتر بكتير من ألومنيوم. النتيجة: الموديل بقى **متحيّز للبلاستيك** وبرضه مش بيحدد مكان الحاجة.

**النسخة التالتة (V3):** قلنا نصلّح الليبلز أوتوماتيك — استخدمنا خوارزميات كلاسيكية (زي GrabCut) تولّد بوكسات أضيق بنفسها. المشكلة إن البوكسات المتولّدة كانت غلط في حالات كتير… **وتدريب موديل على ليبلز غلط أسوأ من قلة الداتا**. الأداء نزل. الدرس المستفاد: **عمرك ما تفبرك الليبلز**.

**النسخة الرابعة (V4) — اللي شغالة دلوقتي:** غيّرنا الاستراتيجية من جذورها:
- **بوكسات حقيقية متعلّمة بإيد بشر فقط** — ولا بوكس واحد متولّد أو متحرّك.
- دمجنا **٤ داتاسِتس Detection** حقيقية: Drinking Waste و Beverage Containers و YOLO Waste Detection و Can-Bottle-Pack.
- عملنا **خريطة كلاسات متحقق منها يدوياً** لكل داتاسِت: يعني "إزازة زجاج" أو "غطاء" أو "كوباية" بتترفض، مش بتتحسب غلط. (وفي داتاسِت اسمه TACO استبعدناه بالكامل لأن الليبلز بتاعته كانت كلاس واحد "زبالة" — مش نافع.)

المحصلة: **١١,٨٩٧ صورة** فيها **١٦,٧٧٢ بوكس حقيقي** — **٨,٥٣٤ بلاستيك و ٨,٢٣٨ ألومنيوم** — يعني الكلاسين **متوازنين تقريباً بالظبط**، وده اللي بيخلي الأرقام اللي جاية تستحق الثقة. وقسمنا الداتا **٨٠/١٠/١٠**: تدريب ١٠,٣٢٧ / تحقق ٩٧٨ / اختبار ٥٩٢.

---

## 🟢 سلايد ١٨ — AI · MODEL & TRAINING (حوالي ٣٥ ثانية)

اخترنا **YOLOv8s** — موديل Object Detection بـ **١١.١ مليون باراميتر**:
كبير كفاية يدّي دقة عالية، وصغير كفاية يشتغل Real-Time على لابتوب الماكينة.

ومبدأناش من الصفر — استخدمنا **Transfer Learning** من موديل متدرّب على COCO،
ودرّبنا **١٠٠ إيبوك** على **كارتين Tesla T4** على Kaggle، بأوبتيمايزر **AdamW** و learning rate **0.001**،
مع **Early Stopping (patience 20)** عشان نوقف قبل الـ Overfitting.
منحنيات التدريب على السلايد بتوضح إن الـ Loss نزل بسلاسة والـ mAP طلع من غير تذبذب — يعني تدريب صحّي.

---

## 🟢 سلايد ١٩ — AI · DIAGNOSTICS (حوالي ٣٥ ثانية)

قبل الأرقام النهائية، بنشخّص الموديل بـ **Confusion Matrix**:
- **٩٣٪** من البلاستيك الحقيقي اتعرف عليه بلاستيك ✔
- **٩٩٪** من الألومنيوم الحقيقي اتعرف عليه ألومنيوم ✔
- والأهم: الخلط **بين البلاستيك والألومنيوم نفسهم تقريباً صفر** — يعني الماكينة مش هتحط كانز في صندوق البلاستيك.

الغلط الوحيد الحقيقي هو الخلط مع الـ **Background** — يعني الموديل ساعات يشك في حاجة مش موجودة أو يفوّت حاجة. وده بالظبط اللي بوابة الـ **٦٥٪** بتفلتره في الماكينة الحقيقية.

---

## 🟢 سلايد ٢٠ — AI · EVALUATION بالتفصيل (حوالي دقيقة) ⭐ أهم سلايد

**النقطة الجوهرية الأولى: كل الأرقام دي على Test Set محجوز — ٥٩٢ صورة الموديل عمره ما شافها، لا في التدريب ولا في الضبط.** ده اختبار نزيه ١٠٠٪.

**الأرقام الأربعة:**

- **mAP@0.5 = 0.928** — ده المقياس الرئيسي في الـ Object Detection. معناه: متوسط دقة الموديل لما نعتبر التوقع صح لو البوكس بتاعه متداخل مع البوكس الحقيقي بنسبة **٥٠٪ على الأقل** (الـ IoU). إحنا حطينا هدف في أول المشروع **أكبر من 0.90** — وعدّيناه ✔

- **mAP@0.5:0.95 = 0.687** — نفس الفكرة بس **أصعب بكتير**: بنحسب المتوسط على عتبات تداخل من ٥٠٪ لغاية ٩٥٪. يعني بيقيس مش بس "لقى الحاجة" لكن "**رسم البوكس مظبوط بالمليمتر ولا لأ**". الرقم ده دايماً أقل بطبيعته، و0.687 رقم قوي.

- **Precision = 0.924** — من كل ١٠٠ مرة الموديل قال "دي إزازة/كانز"، كان صح في ٩٢ منهم. يعني **إنذارات كاذبة قليلة** — مهم عشان الماكينة متديش نقط ببلاش.

- **Recall = 0.864** — من كل ١٠٠ حاجة حقيقية موجودة، الموديل لقط ٨٦ منهم. يعني ممكن يفوّت شوية — وده مقبول عندنا، لأن في الماكينة المستخدم بيثبّت الحاجة قدام الكاميرا والموديل بيحلل فريمات كتير متتالية، فاللي بيفوت في فريم بيتلقط في اللي بعده.

**على مستوى كل كلاس (Per-Class AP):**
- **الألومنيوم: 0.986** — شبه مثالي، لأن شكله المعدني مميز جداً.
- **البلاستيك: 0.870** — أصعب، لأن الإزازة البلاستيك **شفافة** وبتاخد لون الخلفية، وأشكالها كتير. ودي أول حاجة في خطة التطوير: نعمل Fine-Tuning على صور كاميرا الماكينة نفسها.

**السرعة:** **٦٩ فريم/ثانية** على GPU يعني **١٤.٥ مللي ثانية** للفريم، وحتى على CPU عادي حوالي **٨٧ مللي ثانية** — وهدفنا كان أقل من ثانية، فإحنا أسرع من الهدف بأكتر من ١٠ أضعاف.

---

## 🟢 سلايد ٢١ — FROM NOTEBOOK TO MACHINE (حوالي ٤٠ ثانية)

إزاي الموديل ده بيشتغل جوه الماكينة فعلياً؟ خط أنابيب من ٥ خطوات:

**الكاميرا** بتلقط فريم ← **YOLOv8s** بيحلله ← **طبقة القرار**: لازم الثقة تعدي **٦٥٪** *و* نفس الحاجة تفضل ثابتة قدام الكاميرا **١.٢ ثانية** — الشرط التاني ده بيمنع أي لقطة عابرة أو خطأ لحظي إنه يتحسب ← **الأردوينو** بياخد أمر بالسيريال يفتح البوابة الصح ← **الباك إند** بيتسجل فيه المعاملة والنقط فوراً.

وليه ٦٥٪ بالذات؟ بصّوا على الهيستوجرام: توزيع الثقة لما في حاجة حقيقية بيبقى عالي فوق البوابة، والضوضاء بتقع تحتها — البوابة قاعدة في المكان الفاصل بالظبط، وحوالي **٥٢٪** من كل القراءات هي اللي بتعدي. وصدّرنا الموديل **PyTorch و ONNX** عشان يشتغل على أي جهاز.

---

## 🟢 سلايد ٢٢ — HARDWARE · ARDUINO (حوالي ٤٥ ثانية)

الجزء الميكانيكي بسيط بتعمّد — **البساطة هنا قرار هندسي**:

- **Arduino Nano** + **٢ سيرفو SG90**: سيرفو لبوابة البلاستيك على **D9** وسيرفو للألومنيوم على **D10**.
- بروتوكول التواصل مع اللابتوب: **بايت واحد** على السيريال بسرعة 9600 —
  حرف **P** يفتح بوابة البلاستيك، **A** الألومنيوم، **T** بيعمل Self-Test.
- الكود جوه الأردوينو **Non-Blocking State Machine** — يعني مفيش `delay()` بيجمّد البورد؛ البوابة بتفتح وتقفل بعداد `millis()` والبورد فاضل صاحي يستقبل أوامر جديدة طول الوقت.
- بعد ما البوابة تقفل بنعمل **detach** للسيرفو — عشان نوقف الاهتزاز والسخونة والضجيج.
- وأول ما البورد ياخد كهربا بيعمل **Self-Test** يفتح ويقفل البوابتين — فبنعرف إن التوصيلات سليمة من غير لابتوب أصلاً.
- ملاحظة قوة مهمة: السيرفو الواحد ممكن يسحب لغاية ٤٠٠+ مللي أمبير وقت الضغط، فالسيرفوهات بتتغذى من **مصدر 5V منفصل** مع **أرضي مشترك** مع الأردوينو — عشان مفيش Brown-out يعمل ريستارت للبورد.

---

## 🟢 سلايد ٢٣ — HARDWARE · INDUSTRIAL DESIGN (حوالي ٢٥ ثانية)

وده التصميم الصناعي للماكينة — مصمم ثلاثي الأبعاد بالكامل:
شاشة الكشك فوق، فتحة الإدخال في المنتصف بحلقة خضرا مضيئة، وصندوقين منفصلين تحت — بلاستيك وألومنيوم — بيتفتحوا بالسيرفو حسب قرار الموديل. التصميم قابل للتصنيع بخامات بسيطة، وواجهته واضحة لأي مستخدم من غير شرح.

**جملة الختام لجزئي:** "يعني باختصار: موديل اتبنى على ٤ نسخ من التجربة والتعلم، بيحقق ٩٢.٨٪ على داتا محجوزة، وهاردوير بسيط وموثوق بينفذ قراره في أقل من ثانية." — وبسلّم للزميل اللي بعدي 👋

---
---

# 📚 حاجات لازم تفهمها كويس (عشان أي سؤال مفاجئ)

1. **IoU (Intersection over Union):** نسبة التداخل بين البوكس المتوقع والبوكس الحقيقي = مساحة التقاطع ÷ مساحة الاتحاد. هي أساس كل مقاييس الـ Detection.
2. **mAP@0.5 vs mAP@0.5:0.95:** الأولانية بتسأل "لقى الحاجة؟" (تداخل ≥ ٥٠٪ يعتبر صح). التانية بتسأل "لقاها **ورسمها مظبوط**؟" (متوسط على عتبات ٥٠٪ حتى ٩٥٪ بخطوة ٥٪). عشان كده التانية دايماً أقل.
3. **Precision vs Recall:** Precision = قد إيه توقعاته نضيفة (قليل الإنذار الكاذب). Recall = قد إيه بيلقط كل الموجود (قليل الفوات). في تعارض بينهم: لو رفعت عتبة الثقة، الـ Precision يزيد والـ Recall يقل. إحنا اخترنا ٦٥٪ كنقطة توازن لصالح الـ Precision — لأن "نقط ببلاش" أسوأ من "المستخدم يقرّب الإزازة تاني".
4. **Open-Set Rejection:** بدل ما نعلّم الموديل كلاس "مجهول" (مستحيل تغطي كل حاجة في الدنيا)، بنستخدم انخفاض الثقة كإشارة رفض.
5. **Transfer Learning:** الموديل جاي متعلم أشكال وحواف وخامات من مليون+ صورة (COCO)، وإحنا بنخصصه لمهمتنا — أسرع وأدق من التدريب من الصفر بكتير.
6. **ليه YOLO مش Classification؟** التصنيف بيقول "الصورة فيها إيه". الـ Detection بيقول "**فين** وإيه" — وإحنا محتاجين مكان الحاجة عشان نتأكد إن في حاجة فعلاً اتحطت جوه الفتحة، مش خلفية.
7. **ليه البلاستيك أضعف من الألومنيوم؟** الشفافية (بياخد لون الخلفية) + تنوع الأشكال والأحجام أكبر بكتير. الحل المخطط: Fine-tuning على صور كاميرا الماكينة نفسها (وإحنا أصلاً بنحفظ كل فريم مقبول عشان الغرض ده).
8. **إزاي متأكدين مفيش Overfitting؟** (أ) Validation set منفصل أثناء التدريب + Early Stopping. (ب) الأرقام النهائية على Test set محجوز تماماً. (ج) منحنيات التدريب: الـ val loss نازل مع الـ train loss مش متباعدين.
9. **الـ 1.2 ثانية Stability Buffer:** الموديل بيتسأل على كل فريم، فقرار واحد غلط في فريم واحد ممكن يدي نقط بالغلط. بنشترط استمرار نفس الكلاس ~١.٢ ثانية (مع تسامح في فريم متقطع) قبل الاحتساب.
10. **في الهاردوير — ليه Arduino مش Raspberry Pi؟** الأردوينو بيتحكم في سيرفوهات بس — مهمة Real-time بسيطة ورخيصة وموثوقة. الذكاء كله على اللابتوب/الجهاز المضيف. Pi هيبقى تكلفة وتعقيد من غير مبرر.
11. **ليه السيرفو بيتفصل (detach) بعد الحركة؟** السيرفو المتصل بيفضل "يقاوم" عشان يثبت على الزاوية → اهتزاز وصوت وسخونة واستهلاك. الفصل بيريّحه والبوابة واقفة بوزنها.

# ❓ الأسئلة المتوقعة من اللجنة (مع إجابات جاهزة)

**س١: ليه معملتوش كلاس تالت لكل حاجة تانية (زجاج/ورق/زبالة)؟**
ج: لأن حجم الـ "Other" (~٤٤ ألف صورة) هيسيطر على الـ Loss ويحيّز الموديل، ومستحيل نغطي "كل حاجة في الدنيا" ككلاس. الحل الأصح علمياً هو Open-Set Rejection ببوابة ثقة — وأثبت فعاليته عملياً.

**س٢: يعني إيه mAP@0.5 بالظبط؟ وليه فيه رقمين؟**
ج: (اشرح تعريف IoU ثم الفرق بين العتبتين — النقطتين ١ و٢ فوق). الرقم الأول بيقيس "الاكتشاف"، والتاني بيقيس "دقة تحديد المكان".

**س٣: الـ Recall عندكم 0.864 — يعني بيفوّت ١٣٪؟ ده مقبول؟**
ج: في سياق الماكينة آه — لأن القرار مش من فريم واحد: المستخدم بيثبت الحاجة والموديل بيحلل عشرات الفريمات، فاحتمال تفويتها في كل الفريمات ضئيل جداً. والأهم إن الـ Precision عالي (0.924) عشان محدش ياخد نقط بالغلط.

**س٤: إيه ضمان إن مفيش Data Leakage بين التدريب والاختبار؟**
ج: التقسيم ٨٠/١٠/١٠ اتعمل على مستوى الصور قبل التدريب، والـ Test set (٥٩٢ صورة) ما دخلش لا في التدريب ولا في اختيار الهايبر باراميترز — بيتقاس مرة واحدة في الآخر.

**س٥: جربتوا موديلات تانية غير YOLOv8s؟ ليه s بالذات؟**
ج: عائلة YOLOv8 بتيجي بأحجام (n/s/m/l/x). اخترنا s كنقطة التوازن: أدق من n بشكل ملموس، وأسرع بكتير من m/l على جهاز الماكينة — والقياس أثبت 69 FPS على GPU و~87ms على CPU، وده أكتر من كافي للـ Real-time.

**س٦: لو حطيت إزازة زجاج، هيحصل إيه؟**
ج: الزجاج مش من الكلاسين المتدربين، فالموديل غالباً مش هيدي ثقة ≥٦٥٪ لأي كلاس → الماكينة بترفض العنصر ومفيش نقط. (ودي بالظبط وظيفة الـ Open-Set Rejection.)

**س٧: ليه البلاستيك 0.870 والألومنيوم 0.986؟**
ج: الشفافية وتنوّع الأشكال (نقطة ٧ فوق) + خطتنا للتحسين: fine-tuning على صور كاميرا الماكينة الحقيقية اللي بنجمعها تلقائياً.

**س٨: قولتوا في نسخة قديمة كانت بتكتشف حاجات وهي الماكينة فاضية — إيه اللي كان بيحصل؟**
ج: V1–V2 اتدربوا على بوكسات = الصورة كلها (من داتاسِتس تصنيف)، فالموديل اتعلم يصنّف "الفريم كله" بدل ما يحدد جسم. لما شاف خلفية الماكينة، صنّفها. الحل الجذري في V4: بوكسات حقيقية ضيقة فقط — فالموديل بقى يتعلم "فين الجسم" فعلاً.

**س٩: ليه رفضتوا التوليد الأوتوماتيكي للبوكسات (V3)؟ مش ده Data-Centric AI؟**
ج: جربناه فعلاً — خوارزميات segmentation كلاسيكية بتغلط في الظلال والانعكاسات والخلفيات المعقدة، فبتنتج ليبلز غلط، والموديل بيتعلم الغلط بثقة. Data-centric الصحيح هو تحسين **جودة** الليبلز مش فبركتها — وده اللي عملناه في V4 (بوكسات بشرية + خرائط كلاسات متحقق منها يدوياً).

**س١٠: إيه اللي يحصل لو النت قطع لحظة ما حد رمى إزازة؟**
ج: الماكينة بتفتح البوابة وبتحسب محلياً، والمعاملة بتتخزن في طابور على القرص وبتتبعت أول ما النت يرجع — النقط عمرها ما بتضيع. (ودي من نقاط المتانة اللي بنفتخر بيها.)

**س١١: السيرفو SG90 ضعيف — يشيل بوابة حقيقية؟**
ج: للنموذج الأولي آه، البوابة خفيفة ومحور الدوران متزن. في نسخة الإنتاج هنستخدم سيرفو معدني أقوى (MG996R مثلاً) — نفس الكود والبروتوكول بالظبط، تغيير قطعة بس.

**س١٢: ليه البروتوكول بايت واحد؟ مش بدائي؟**
ج: بالعكس — ده قرار موثوقية: مفيش parsing يغلط، ومفيش حالة تعلّق، وسهل تختبره يدوياً من أي Serial Monitor. والبورد بيرد بـ ACK/DONE فاللابتوب متأكد إن الأمر وصل واتنفذ.

**س١٣: لو السيرفوهات سحبت تيار عالي؟**
ج: محسوبة: تغذية منفصلة 5V/2A للسيرفوهات + Common Ground مع الأردوينو، فمفيش Brown-out على البورد. وجربناها عملياً بالـ Self-Test والـ bench tester.

**س١٤: إيه الفرق بين نتايجكم دي ونتايج الورق المنشورة على نفس الداتاسِتس؟**
ج: مش قابلة للمقارنة المباشرة لأن إحنا عاملين دمج مخصوص لكلاسين بس بخرائط منقحة — لكن كمرجع، هدفنا الهندسي (>0.90 mAP@0.5) متجاوز، والقياس على test محجوز.

**س١٥ (لو حد سأل عن الأخلاقيات/الخصوصية):**
ج: كاميرا الماكينة بتصور منطقة الإدخال بس (مش وشوش)، والصور المحفوظة للتحسين محلية وبتتمسح دورياً (بنحتفظ بآخر ٣٠٠ فريم بس).

# 💡 اقتراحات مني ليك وانت بتقدم

1. **قصة الـ ٤ نسخ هي أقوى ورقة عندك.** اللجان بتحب "جرّبنا، فشلنا، فهمنا ليه، صلّحنا" أكتر بكتير من "عملنا موديل وجاب ٩٣٪". خد وقتك فيها.
2. **عرّف كل مقياس قبل ما تقول رقمه** (سلايد ٢٠). أستاذ الـ AI هيقدّر إنك فاهم مش حافظ.
3. لو في وقت، **شغّل `python test_webcam.py` لايف** أو فيديو مسجل للكشف — لقطة الإطار الأخضر بيتقفل على الإزازة أقوى من أي سلايد.
4. **متقولش "دقة" وخلاص** — قول "mAP على test set محجوز" — الدقة الـ accuracy مصطلح تصنيف وهيتحسب عليك.
5. لو سألوك سؤال متعرفوش: "جربناش السيناريو ده تحديداً، بس التصميم بيسمح نختبره عن طريق كذا…" — أفضل مليون مرة من إجابة مخترعة.
6. الرابط بين جزئك وجزء الباك إند: "الموديل بيقرر، الأردوينو بينفذ، **والباك إند بيوثّق**" — جملة تسليم حلوة للزميل اللي بعدك.

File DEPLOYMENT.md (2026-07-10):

# Deploy Keep It Green for free (so anyone can try it)

## What actually goes online
You only host **one thing**: the .NET backend. It already serves the **web app** (`wwwroot`) and the **kiosk page** (`/kiosk/`) too, and it needs **one SQL Server database**. So "online" = **1 web app + 1 SQL DB**.

| Part | Where it lives |
|---|---|
| Backend API + Web app + Kiosk page | **Hosted** (public HTTPS URL) |
| SQL Server database | **Hosted** (free MSSQL) |
| Mobile app (APK) | **Distributed** as a download (GitHub Releases) → points at the hosted URL |
| AI machine (Python + camera) | **Stays on your laptop** — it calls the hosted API; use SIMULATE mode for a demo without hardware |

> The AI machine can't be "hosted" (it needs a real camera). For a public trial, people use the **web app** or the **mobile app**; you run the machine live from your laptop against the same hosted backend.

---

## Best-practice choice
Your stack is **.NET 10 + SQL Server (MSSQL)**. Most free hosts only give Postgres/MySQL, so pick a host that supports **MSSQL** — otherwise you'd have to rewrite the data layer.

### ⭐ Option A — MonsterASP.NET (recommended: easiest, free, no card)
Free ASP.NET Core hosting **+ a free MSSQL database + free HTTPS subdomain** (`yourapp.runasp.net`). Perfect match for this project, zero cost, no credit card.

### Option B — Azure free tier (most "professional")
**App Service (F1 free)** + **Azure SQL Database free tier** (genuinely free monthly allowance). Needs a card for identity verification (no charge on free tier). Best if you want it to look enterprise-grade in the defense.

### Option C — Render/Railway/Fly + free Postgres
Only if you **switch the database to PostgreSQL** (change the EF Core provider to Npgsql). More work, but these hosts are modern and Docker-native (a `Dockerfile` is included). Not recommended unless you specifically want it.

---

## Step-by-step (Option A — MonsterASP.NET)

1. **Sign up** at monsterasp.net (free plan). In the panel, create:
   - a **Website** → you get `https://<yourapp>.runasp.net` with free SSL,
   - a **MSSQL database** → copy its **connection string**.

2. **Set secrets on the host** (Environment variables / Connection Strings) — never in code. .NET reads nested keys with a **double underscore**:
   ```
   ConnectionStrings__DefaultConnection = <the MSSQL connection string from the panel>
   jwt__Key      = <a long random secret, 40+ chars>
   jwt__Issuer   = keepitgreen
   jwt__Audience = keepitgreen
   Machine__ApiKey = <a new secret>
   ```
   ⚠️ **Change all three secrets** from the dev defaults (JWT key, Machine key, and the seeded admin password in `Data/SeedData.cs`).

3. **Publish & upload:**
   ```powershell
   cd "D:\Graduation Project\Recycle"
   dotnet publish -c Release -o publish
   ```
   Upload the `publish/` folder via the host's **File Manager / Web Deploy / FTP** (MonsterASP supports all three). Or connect the GitHub repo for auto-deploy.

4. **First run is automatic:** on startup the app applies EF migrations and seeds the admin (`SeedData.InitializeAsync`) — the database creates itself, no manual SQL.

5. **Try it:** open `https://<yourapp>.runasp.net` → the web app. Kiosk demo at `https://<yourapp>.runasp.net/kiosk/?demo`. Admin login `admin@recycle.com` (change the password!).

---

## Point the mobile app at the live server
1. In [Mobile/lib/services/api_service.dart](Mobile/lib/services/api_service.dart) set the default:
   ```dart
   static const String _lanBaseUrl = 'https://<yourapp>.runasp.net';
   ```
   (The in-app **Server settings** screen still lets anyone override it.)
2. Because it's **HTTPS**, cleartext isn't needed anymore. Rebuild:
   ```powershell
   flutter build apk --release
   ```
3. **Distribute the APK for free:** push the repo to GitHub → **Releases** → upload `KeepItGreen.apk` → share the download link (and a QR code). "Anyone can try" = they scan/download, install, and it talks to your live backend. (Alternatively, Firebase App Distribution.)

---

## Best-practice checklist
- ✅ **Secrets in env vars**, never committed; rotate JWT key, `Machine:ApiKey`, and the admin password before going public.
- ✅ **HTTPS only** — free hosts provide it automatically; it also fixes the Android cleartext limitation.
- ✅ **Migrations auto-run on startup** (already wired) — no manual DB setup.
- ⚠️ **Free tiers sleep when idle** (Azure F1 / Render) → the first request is slow (cold start). Add a free **UptimeRobot** monitor pinging the URL every 5 min to keep it warm — this also gives you an uptime page.
- ⚠️ **Free DB size limits** (~0.5–2 GB) — plenty for a demo.
- ✅ **CORS** is already open (`AllowAnyOrigin`) — fine for a demo; tighten to your domain for real production.
- ✅ **Docker option** — a `Recycle/Dockerfile` is included for container hosts (respects `$PORT`).
- ✅ **Back up the DB** the night before the defense (export from the host panel).

---

## Quick "just show the UI" alternative
If you only need people to *see* the web front-end (no live data), you can also drop the Flutter **web build** or the SPA onto **Netlify / Vercel / GitHub Pages / Cloudflare Pages** (all free, drag-and-drop). But the full experience (login, points, redeem) needs the backend — so Option A/B is the real answer.

---

### TL;DR
**MonsterASP.NET** (free .NET + free MSSQL) → set the 3 secrets as env vars → `dotnet publish` and upload → open `https://yourapp.runasp.net`. Point the APK's base URL at that, rebuild, and share it via GitHub Releases. The AI machine stays on your laptop and talks to the same URL.

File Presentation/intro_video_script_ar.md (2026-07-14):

# Keep It Green — سكريبت فيديو الافتتاحية (١:٣٠ دقيقة)

> **Instructions for NotebookLM:** Create a video overview narrated in **Egyptian Arabic (اللهجة المصرية)**.
> Use the narration below **verbatim** — do not translate it or switch to formal Arabic (فصحى).
> Total length: about 90 seconds. One energetic young narrator voice.
> Visual cues per segment are listed under each block.

---

## ⏱ 0:00 – 0:15 — الافتتاحية (Hook)

**النص:**
كل دقيقة بتعدي على الكوكب… بيتباع فيها **مليون** إزازة بلاستيك.
وفي مصر لوحدها؟ حوالي **١٠٠ مليون طن** زبالة كل سنة، منهم **٢.٥ مليون طن بلاستيك**.
والسؤال المحيّر: إحنا فعلاً مش بنحب البيئة… ولا مفيش حاجة بتشجعنا؟

**Visuals:** شوارع فيها مخلفات، إزازات بلاستيك وكانز، أرقام كبيرة تظهر على الشاشة (1M / 100M / 2.5M).

---

## ⏱ 0:15 – 0:30 — الفكرة (The Insight)

**النص:**
الحقيقة؟ الناس عايزة تشارك… بس محدش بيكافئها.
مفيش نظام سهل وسريع يقولّك: "شكراً… خد حقك".
طب تخيّل معايا… لو كل إزازة بترميها بتتحوّل في ثواني لنقط في موبايلك؟

**Visuals:** شخص بيرمي إزازة في صندوق عادي وبيمشي، ثم لقطة انتقالية لموبايل بتظهر عليه نقط بتزيد.

---

## ⏱ 0:30 – 1:00 — الحل (Keep It Green)

**النص:**
من هنا وُلدت فكرة **"Keep It Green"** — خليها خضرا!
ماكينة ذكية شغّالة بالذكاء الاصطناعي:
بتفتح الأبلكيشن، بتعمل مسح للـ QR، وتحط الإزازة أو الكانز…
الكاميرا بتتعرف على نوع الخامة في **أقل من ثانية**،
الماكينة بتفرز البلاستيك من الألومنيوم **أوتوماتيك**،
والنقط بتنزل في حسابك **فوراً** — تستبدلها بخصومات ومكافآت حقيقية.

**Visuals:** الموديل ثلاثي الأبعاد للماكينة بيلف، لقطة مسح QR من الموبايل، إزازة بتدخل، إطار أخضر بيحدد الإزازة على الشاشة، عداد نقط بيزيد (+10).

---

## ⏱ 1:00 – 1:20 — المشروع حقيقي (It's Real)

**النص:**
ودي مش مجرد فكرة على ورق…
ده **نظام كامل شغّال دلوقتي**: موديل ذكاء اصطناعي اتدرّب على حوالي **١٢ ألف صورة حقيقية** بدقة **٩٣٪**،
أبلكيشن موبايل، ماكينة بهاردوير حقيقي، وسيرفر **لايف على الإنترنت** أي حد يجربه.

**Visuals:** سكرين شوت من الأبلكيشن، منحنيات تدريب الموديل، شاشة الكشك وهي بتتعرف على إزازة، عنوان الموقع keepitgreen.runasp.net.

---

## ⏱ 1:20 – 1:30 — الختام (Tagline)

**النص:**
مشروع تخرجنا… رؤيتنا لمصر أنضف وأخضر.
**"Keep It Green… خليها خضرا!"** 🌱

**Visuals:** لوجو Keep It Green على خلفية خضراء غامقة، أسماء الفريق تحت إشراف د. مها طلبة، جامعة المنوفية ٢٠٢٥–٢٠٢٦.

---

## ملاحظات للفيديو (Production notes)

- **الإيقاع:** سريع وحماسي في الافتتاحية، يهدأ شوية في جزء الحل، ويرجع قوي في الختام.
- **الموسيقى:** خلفية خفيفة upbeat، تعلى شوية عند "خليها خضرا".
- **الأرقام دي حقيقية من المشروع:** دقة الموديل ٩٢.٨٪ (mAP@0.5) على بيانات اختبار محجوزة، ١١,٨٩٧ صورة تدريب حقيقية، فرز بلاستيك/ألومنيوم، النظام منشور فعلاً على MonsterASP.
- لو NotebookLM قصّر المدة: أهم حاجة يفضل الترتيب — مشكلة ← فكرة ← حل ← حقيقي ← ختام.

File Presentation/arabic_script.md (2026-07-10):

# 🎤 سكربت العرض التقديمي — مشروع "Keep It Green" (خليها خضرا)

> سكربت كامل باللغة العربية لعرض المشروع أمام لجنة المناقشة. مقسّم حسب تسلسل الشرائح، ومكتوب ليُقرأ بصوتٍ واضح. الأرقام موثّقة في `facts_sheet.md` والنتائج التقنية في `Keep_It_Green_Technical.pptx`.
> الزمن التقديري: 25–30 دقيقة. القاعدة الذهبية: فكرة واحدة لكل شريحة، انطق الرقم ثم اشرح "وإيه يعني".

---

## 🟢 المحور الأول: لماذا المشروع؟ (حوالي ٥ دقائق)

### (١) العنوان والافتتاح
«السلام عليكم. إحنا فريق **Keep It Green**. بنينا ماكينة إعادة تدوير ذكية بتكافئك على كل زجاجة أو علبة بترجّعها — إعادة تدوير عكسية مدعومة بالذكاء الاصطناعي، متصمّمة لمصر.»
*(قدّم أعضاء الفريق في سطر واحد، وابدأ بطاقة.)*

### (٢) المشكلة — الحجم العالمي
«كل دقيقة، العالم بيشتري **مليون زجاجة بلاستيك** — يعني حوالي **نصف تريليون زجاجة في السنة**. ومع كل ده، **٩٪ بس** من البلاستيك بيتعاد تدويره؛ الباقي بيروح المدافن أو الحرق أو بيتسرّب للطبيعة.»
«دي مش مشكلة سلوك… دي مشكلة **نظام**: مفيش سبب يخلّي الناس تدوّر.»

### (٣) المشكلة في مصر
«المشكلة على بابنا: مصر بتنتج حوالي **١٠٠ مليون طن مخلفات في السنة**، ومعدل تدوير البلاستيك لسه حوالي **٣٧٪** بس. الخبر الحلو إن الدولة مستهدفة **٦٠٪ بحلول ٢٠٢٧** — يعني السياسة والضغط ماشيين في اتجاهنا.»

### (٤) ليه الناس مش بتدوّر؟
«لو سألت أي حد ليه مش بيدوّر، الإجابة مش "مش مهتم". الإجابة: **مفيش مكافأة**، و**مش مريح**، و**التأثير مش واضح**. لو حلّينا التلاتة دول، السلوك بيتغيّر.»

---

## 🟢 المحور الثاني: ما هو الحل؟ (حوالي ٧ دقائق)

### (٥) الفكرة: الحوافز تنجح
«إحنا عارفين إن ده بينجح. **ألمانيا بترجّع ٩٨٪** من عبواتها، و**النرويج ٩٧٪** — والفرق مش ثقافة، الفرق **مكافأة** بتتوصّل عن طريق ماكينات إعادة التدوير العكسية. مصر لسه **مفيهاش طبقة المكافأة** دي. والفجوة دي هي الفرصة بتاعتنا.»

### (٦) الحل: Keep It Green (مع نموذج ٣D)
*(شغّل فيديو الماكينة ثلاثي الأبعاد.)*
«دي الماكينة بتاعتنا. بتحط زجاجة أو علبة، الكاميرا بتتعرّف عليها، والنقاط بتوصل موبايلك **فورًا** — من غير قانون تأمين، من غير باركود، من غير موظفين.»

### (٧) إزاي بيشتغل
«ثلاث خطوات: **اربط زي الـ ATM** (امسح كود QR أو اكتب كود مكوّن من ٦ أرقام)، **حط العنصر** والذكاء الاصطناعي بيأكّده، **النقاط بتنزل** وتستبدلها من التطبيق. كل ده في أقل من دقيقة.»

### (٨) الفرز الآلي
«لما الكاميرا بتقرّر، **الأردوينو بيفتح القسم الصح** — البلاستيك في ناحية والألومنيوم في ناحية. ده **هاردوير شغّال**، مش موك أب.»

### (٩) تطبيق الموبايل
«طبقة المكافأة عايشة في جيبك: امسح واربط، شوف نقاطك بتوقيت القاهرة، واستبدلها بمكافآت من التجار — والكود مايظهرش غير بعد ما تستبدل.»

### (١٠) شاشة الماكينة (الكشك)
«شاشة الماكينة مقصود إنها بسيطة زي الـ ATM: حط عنصر… وتخلص بملخّص واضح للنقاط — المكتسبة والإجمالي.»

---

## 🟢 المحور الثالث: كيف بُنِي؟ — الجزء التقني (حوالي ٧ دقائق)

### (١١) الذكاء الاصطناعي — العقل
«العقل هو نموذج رؤية حاسوبية **YOLOv8s** بيصنّف كل عنصر لحظيًا. **فئتين بس**: زجاجة بلاستيك وعلبة ألومنيوم. واخترنا **فئتين مش أكتر** عن قصد؛ لأن البيانات الخام كانت غير متوازنة بشدّة (فئة "أخرى" فيها ٤٤ ألف صورة مقابل ٤ آلاف بلاستيك وألف ألومنيوم).»
«بدل ما ندرّب فئة "أخرى" عملاقة، بنستخدم **حدّ الثقة**: أي عنصر ثقته أقل من **٠.٦٥** بيترفض كغير قابل للتدوير. ده اسمه open-set rejection.»

### (١٢) البيانات
«دمجنا **٤ مجموعات بيانات عامة** في مجموعة واحدة نظيفة: **٤١١٣ صورة** (٣٢٢٠ تدريب / ٤٨٣ تحقّق / ٤١٠ اختبار)، و**٤٦٤٤ صندوق** (٢٧٣٩ بلاستيك و١٩٠٥ ألومنيوم). وحّدنا الدقة على **٦٤٠ بكسل**.»

### (١٣) التدريب
«درّبنا **١٠٠ epoch** على **كارتين T4** على Kaggle، بـ AdamW ومعدّل تعلّم ٠.٠٠١، مع **زيادة بيانات قوية** (mosaic و mixup و copy-paste وتدوير وقلب). استخدمنا **transfer learning** من أوزان COCO — فالنموذج أصلاً عارف الحواف والأشكال، إحنا بس علّمناه عنصرينا.»

### (١٤) النتائج على مجموعة الاختبار
«على بيانات **ماشفهاش النموذج خالص** في التدريب:
- **mAP@0.5 = ٠.٩٢٢** (المستهدف كان أكبر من ٠.٩٠ → **نجاح**)،
- **mAP@0.5:0.95 = ٠.٨٨٤**، **Precision = ٠.٩٤٩**، **Recall = ٠.٨٦٦**.
- ولكل فئة: البلاستيك ٠.٩١٤ والألومنيوم ٠.٩٣١ — الاتنين فوق خط الـ ٠.٩٠.»
«ومصفوفة الالتباس بتوضّح إن اللبس بين البلاستيك والألومنيوم **شبه معدوم**.»

### (١٥) السرعة
«الشرط: أقل من ثانية للعنصر. النموذج بيوصل **٥٢ إطار في الثانية** على الـ GPU، وحوالي **١١٥ ملّي ثانية** تقدير على لابتوب — تحت حدّ الثانية بمراحل.»

### (١٦) البنية المعمارية
«خمس مكوّنات وتدفّق واحد: ماكينة الذكاء الاصطناعي، سيرفر **.NET 10** على **SQL Server**، تطبيق **Flutter**، لوحة ويب، وهاردوير **أردوينو**. المهم: **مفيش حاجة بتلمس قاعدة البيانات مباشرة** — كل طلب بيعدي على السيرفر وهو موثّق.»

### (١٧) الأمان وعزل الجلسات
«كل إجراء موثّق ومقيّد بالدور: **JWT** للمستخدمين، ومفتاح سري **X-Machine-Key** للماكينة، وكل عملية بتتحسب **للمستخدم المربوط بالجلسة** بس. وأثبتنا العزل بـ **١٣ اختبار من ١٣** على السيرفر الحيّ: كل كود فريد، ومربوط بمستخدم واحد، ومحدش يقدر يخطف جلسة حد تاني.»

### (١٨) الاختبار والجودة
«مش مجرد سلايدات — نظام شغّال ومختبَر. كتبنا اختبارات آلية شاملة: **٢٣ من ٢٣** للمسار الأساسي و**١٢ من ١٢** لمسار الأدمن، كلها ناجحة على **بيئة الإنتاج الحقيقية**. والتطبيق **flutter analyze نضيف تمامًا**.»

### (١٩) النشر — النظام حيّ فعلًا
«المشروع **منشور ومتاح** على **MonsterASP.NET** (استضافة .NET وقاعدة SQL مجانًا، مع HTTPS) على الرابط **keepitgreen.runasp.net** — الويب والكشك والـ API كلهم من نفس المكان. أي حد يقدر يجرّبه دلوقتي.»

---

## 🟢 المحور الرابع: الجانب التجاري (حوالي ٦ دقائق)

### (٢٠) السوق
«سوق ماكينات إعادة التدوير العكسية حوالي **مليار دولار** دلوقتي، ومتوقّع يوصل **٢ مليار بحلول ٢٠٣٠**. سوق التدوير في مصر بينمو كمان. نقطة انطلاقنا: **القاهرة** — الجامعات والمولات ومقرّات الشركات.»

### (٢١) ليه مصر ودلوقتي
«التوقيت مثالي: **١١٣ مليون نسمة**، **متوسط العمر ٢٤ سنة**، **٩٧٪ اتصالات موبايل**. تطبيق مكافآت يعتمد على الموبايل بيتناسب تمامًا — بالإضافة لهدف الـ ٦٠٪ القومي اللي بيدفع في صفّنا.»

### (٢٢) نموذج العمل
«بنكسب وإحنا بننضّف: التجار بيدفعوا مقابل العروض اللي المستخدمين بيستبدلوها، وبنبيع الخامة المستردّة، بالإضافة للرعاية وعقود الاستدامة (ESG) والبيانات. ولاحظوا: **الألومنيوم بـ ١٣٣٨ دولار للطن مقابل ٢١٥ للبلاستيك** — علشان كده بنكافئ الألومنيوم أكتر؛ النقاط بتعكس القيمة الحقيقية.»

### (٢٣) المنافسة
«اللاعبين العالميين (زي TOMRA) محتاجين قوانين تأمين وباركود. إحنا **مش محتاجين ولا واحد فيهم** — الكاميرا بتقرأ العنصر مباشرة. وده اللي بيخلّينا الأنسب لسوق ناشئ مفيهوش نظام تأمين قومي.»

---

## 🟢 المحور الخامس: الخاتمة (حوالي ٤ دقائق)

### (٢٤) الأثر
«العائد حقيقي: إعادة تدوير الألومنيوم بتستهلك **طاقة أقل بـ ٩٥٪** من تصنيعه جديد. الخامة بترجع للاقتصاد بدل ما تروح النيل، والماكينات بتخلق مكافآت وفرص عمل خضراء.»

### (٢٥) الفريق
«فريق متكامل بنى منتج حقيقي:
- **يوسف بدر** — قائد الفريق · الذكاء الاصطناعي والهاردوير
- **إسلام مدحت** — ذكاء اصطناعي
- **أحمد أنور** — ذكاء اصطناعي
- **مهند أيمن** — تطبيق الموبايل
- **منة أسامة** — الواجهة الأمامية
- **شهد الأسود** — الباك إند»

### (٢٦) الرؤية والطلب
«**مصر أكثر خضرة… زجاجة بزجاجة.** إحنا بندوّر على موقع تجريبي، وتمويل، وإرشاد علشان نوصل هناك. شكرًا — ونستقبل أسئلتكم بكل سرور.»

---

## ❓ أسئلة متوقعة وإجاباتها (Q&A)

**دقة النموذج، وإيه اللي بيحصل لعنصر مشفوش قبل كده؟**
«نموذج من فئتين مع حدّ ثقة ٠.٦٥، وكمان **مخزن تأكيد ١.٢ ثانية** — فالعناصر منخفضة الثقة أو الغريبة بتترفض بدل ما تتكافأ بالغلط. والصور المُلتقطة بتتغذّى لإعادة التدريب مستقبلًا.»

**إيه اللي بيمنع الغش؟**
«العملية بتتحسب للجلسة المربوطة بس، والماكينة بتتوثّق بمفتاح سري، وفيه فترة تهدئة ومنع للعدّ المزدوج. وحسّاس الوزن في خطة التطوير.»

**ليه مش باركود زي التطبيقات التانية؟**
«الباركود محتاج ملصق واضح وقاعدة بيانات منتجات. الكاميرا بتصنّف **الخامة نفسها** — فبتشتغل على عبوات مكرمشة أو من غير ملصق، وده الواقع الفعلي في مصر.»

**إيه الفرق بينكم وبين TOMRA؟**
«TOMRA بتعتمد على قوانين تأمين قومية وهاردوير غالي. إحنا بنكافئ عن طريق التطبيق من غير نظام تأمين، وبتكلفة أقل بكتير — متصمّمين للأسواق اللي معندهاش DRS.»

**نموذج الربح؟**
«مكافآت مموّلة من التجار + بيع الخامة المستردّة (الألومنيوم ~١٣٣٨ دولار/طن) هما الأساس؛ والرعاية وعقود ESG والبيانات بيضيفوا. المسارات الغنية بالألومنيوم بتغطّي تكلفتها من الخامة لوحدها.»

**الهاردوير حقيقي ولا محاكاة؟**
«حقيقي: سيرفوهات بيحرّكها أردوينو بتفتح القسم الصح، وفيه برنامج ماكينة شغّال بيدير الكاميرا والواجهة. وعندنا كمان تصميم الصناديق جاهز للطباعة/التصنيع.»

**الأمان وبيانات المستخدم؟**
«توثيق JWT، فصل الأدوار، مفيش وصول مباشر لقاعدة البيانات، ومفيش بيانات شخصية حسّاسة أبعد من أساسيات الحساب. الأوقات بتوقيت القاهرة، والأسرار بتتغيّر قبل النشر.»

**أكبر خطر بصراحة؟**
«اقتصاديات التوزيع وتوريد التجار عند التوسّع. بنقلّل الخطر ببداية تجريبية في الجامعات علشان نثبت معدلات الاستبدال قبل ما نلتزم بكميات هاردوير.»

---
### 💡 نصائح للإلقاء
- ابدأ بقوة برقم "مليون زجاجة في الدقيقة"، وسيبه يوصل قبل ما تكمّل.
- على شريحة الماكينة ثلاثية الأبعاد، سيب الفيديو يتكلّم — قلّل الكلام.
- على الشرائح التقنية، انطق الرقم (٠.٩٢٢ mAP) الأول، وبعدها اشرح معناه ببساطة.
- اقفل بالرؤية: "مصر أكثر خضرة، زجاجة بزجاجة" — بابتسامة وثقة.

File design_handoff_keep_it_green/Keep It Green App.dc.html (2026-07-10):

01 · Welcome / Auth

9:41● ● ▮

Keep It Green

Recycling that rewards you.

Scan a machine, drop your bottles and cans, and stack up points for real perks.

Create account

I already have an account · Log in

02 · Home

9:41● ● ▮

Welcome back

Hi, Lina

L

Your points

1,240pts

≈ 3 rewards ready to redeem

Scan a machine

→

Nearby machines

Riverside Park

Online · 0.3 km

Central Mall

Online · 1.1 km

03 · Scan QR

9:41● ● ▮

←Scan machine

Point at the QR on the machine

04 · Live session

9:41● ● ▮

Connected · Riverside Park

✓

Plastic bottle

96% confident · accepted

+15 pts

1,255pts total

This session · 3 items

Plastic bottle+15

Aluminum can+20

Finish session

05 · Rewards catalog

9:41● ● ▮

Rewards

1,240 pts

20% off

Café Verde

300 pts

Free tote

GreenMart

450 pts

Movie ticket

CineCity

800 pts

15% off

UrbanBikes

600 pts

06 · Redeemed

9:41● ● ▮

✓

Redeemed!

Café Verde · 20% off drinks

Your code

GREEN20

Show this code at checkout.

New balance · 940 pts

Done

07 · Activity history

9:41● ● ▮

Activity

Today

P

Plastic bottle

Riverside Park

+15

A

Aluminum can

Riverside Park

+20

This week

★

Redeemed · Café Verde

20% off

−300

P

Plastic bottle

Central Mall

+15

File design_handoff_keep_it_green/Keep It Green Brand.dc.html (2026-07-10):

Keep It Green

Brand Guidelines · v1.0 · Jun 2026

# Keep It Green

Recycling that rewards you.

Scan a machine, drop your bottles and cans, and watch your points stack up — real perks for keeping the city clean.

Recycle Earn Repeat

Upbeat/ Encouraging/ Effortless/ A little bit game

01 — The Mark

## A leaf that's also a reward.

The mark is a single clean leaf set in a rounded token — the same shape your points live in. Veins double as motion lines: the brand always feels like it's growing. Built on a strict circular grid so it stays crisp from app icon to machine panel.

28%

corner radius

1 : 1

token ratio

32px

min size

02 — Logo system

## Five ways to wear it.

Keep It Green Primary · horizontal

KIG Monogram

Keep It Green

Mark only

Reversed / mono

03 — Color

## Green leads. Sun rewards.

Spring Green

Primary · #18C964

Mark, CTAs, accents

Deep Forest

Dark surface · #0C3B2A

Hero, machine panels

Sun

Reward accent · #FFC83D

Points, badges, coins

Mint

Tint surface · #DCF1E2

Paper

Background · #F6F7F1

Charcoal

Text · #13201A

04 — Typography

## Geometric voice, friendly body.

DisplaySpace Grotesk

Aa

Drop it. Earn it. Repeat.

Regular · Medium · Bold — A B C D E F G 0 1 2 3 4 5

BodyHanken Grotesk

Aa

Every bottle you recycle adds points to your balance. Redeem them for promo codes and discounts from partner vendors near you.

Regular · Medium · Semibold · Bold

Display 52Space Grotesk · Bold

Heading 32Space Grotesk · Bold

Subtitle 22Space Grotesk · Medium

Body 17Hanken Grotesk · Regular

Label 13 · UppercaseSpace Grotesk · Medium

05 — Motion

## Everything feels like a reward.

Springy, bouncy, satisfying. Actions land with a small overshoot; points always count up; the leaf gently grows. Never stiff, never slow.

Pop in

Overshoot · 0.9s

+

The drop

Item accepted

250pts

Count up

Points reward

06 — In context

## Where it shows up.

Ready when you are

Scan the QR with your app to start

Machine welcome screen

Keep It Green

250 pts

App icon

Keep It Green

Graduation Project · Brand Identity v1.0 · Next: app, machine UI & website

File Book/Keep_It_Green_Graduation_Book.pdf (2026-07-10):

### Menoufia University Faculty of Electronic Engineering

### Department of Computer Science & Engineering

### Graduation Project

# Keep It Green

### An AI-Powered Smart Recycling and Reward System

A graduation project submitted in partial fulfilment of the requirements for the degree of B.Sc. in Computer Science & Engineering

By
Yousef Badr
Eslam Medhat
Ahmed Anwer
Mohanad Ayman
Menna Osama
Shahd El Aswad
Supervisor | Head of the Department | Dean
Dr. / [Supervisor Name] | Prof. Dr. / [Head Name] | Prof. Dr. / [Dean Name]

Academic Year 2024 - 2025

Keep It Green — Graduation Project

### Approval Sheet

This is to certify that the graduation project entitled “Keep It Green — An AI-Powered Smart Recycling and Reward System” has been carried out by Yousef Badr, Eslam Medhat, Ahmed Anwer, Mohanad Ayman, Menna Osama, and Shahd El Aswad, under supervision, in the Department of Computer Science & Engineering, Faculty of Electronic Engineering, Menoufia University, and is approved in partial fulfilment of the requirements for the degree of Bachelor of Science in Computer Science & Engineering.

Supervisor:
Name: | Signature: |

Examiner (1):
Name: | Signature: |

Examiner (2):
Name: | Signature: |

Head of the Department:
Name: | Signature: |

Date: ......../......../ 2025

### Abstract

Egypt generates on the order of one hundred million tonnes of solid waste each year and, despite rapid recent progress, still fails to recover a large fraction of its recyclable beverage containers. The evidence from deposit-return countries such as Germany and Norway — where container-return rates exceed ninety-five per cent — shows that the decisive missing ingredient is not public awareness but an immediate, tangible reward for returning each container, a reward layer that Egypt currently lacks because it has neither national deposit legislation nor the barcode infrastructure such schemes require.

This project, Keep It Green, supplies that missing reward layer using artificial intelligence rather than legislation. It couples an AI-powered reverse-vending machine with a mobile reward application, a web dashboard, an on-machine kiosk, and a secure cloud backend. A user pairs their phone with the machine using an ATM-style six-digit code; a camera on the machine runs a YOLOv8 object-detection model that classifies each inserted item as a plastic bottle or an aluminium can; an Arduino opens the correct sorting compartment; and reward points are credited to the paired user instantly through the authenticated backend, later redeemable for partner-vendor offers.

The detector was trained on a unified dataset of 11,897 real-box images fused from four public detection datasets and achieves a mean Average Precision (mAP@0.5) of 0.928 on a held-out test set — exceeding the 0.90 target — while running well within the one-second real-time budget. The complete system was deployed publicly over HTTPS and validated end-to-end with forty-eight automated checks (23 core, 12 administrative, 13 multi-user isolation), all passing. This document describes the motivation, analysis, design, implementation, testing, and deployment of every part of the system in detail.

Keywords: reverse vending, object detection, YOLOv8, recycling incentives, .NET, Flutter, Arduino, Internet of Things, circular economy.

### Abstract (Arabic) — ملخص

يهدف هذا المشروع، »حافظ على األخضر«، إلى معالجة تدّني معدالت إعادة تدوير العبوات في مصر من خالل بناء نظام ذكي السترجاع العبوات ومكافأة المستخدم. يستخدم النظام آلة مزّودة بكاميرا ونموذج ذكاء اصطناعي
)8YOLOv )للتعّرف على الزجاجات البالستيكية وعلب األلمنيوم وفرزها آلًيا، بينما يقترن هاتف المستخدم باآللة عبر رمز مكّون من ستة أرقام على غرار أجهزة الصّراف اآللي، فُتضاف النقاط إلى حسابه فوًرا عبر خادم آمن يمكن استبدالها الحًقا بعروض من شركاء تجاريين.

حقق النموذج متوسط دقة قدره ،0.928 وهو أعلى من الهدف المحدد )0.90(، مع أداء لحظي. وقد جرى التحقق من النظام بالكامل عبر ثماٍن وأربعين اختباًرا آلًيا نجحت جميعها، وُنشر على اإلنترنت بأمان ليتمكن أي شخص من تجربته.

### Acknowledgements

We would like to express our sincere gratitude to our supervisor and to the staff of the Department of Computer Science & Engineering, Faculty of Electronic Engineering, Menoufia University, for their guidance and support throughout this project. We thank our families for their patience and constant encouragement, and we thank one another — each member of the team — for the dedication and collaboration that turned an idea into a working, deployed system.

## Table of Contents

(In Microsoft Word, right-click this table and choose “Update Field” to fill in the page numbers.)

### List of Figures

Figure 5.1 The dataset unification pipeline, from four raw sources to an augmented training set.....45

Figure 5.4 Bounding-box geometry: the boxes are real, human-drawn annotations — only about 1%

Figure 5.8 Per-class Average Precision at IoU 0.5; aluminium clears the 0.90 target and plastic sits

Figure 5.10 Distribution of detection confidence on the test set, with the 0.65 rejection threshold

### List of Tables

### List of Abbreviations

Abbreviation | Meaning
AI | Artificial Intelligence
AP / mAP | Average Precision / mean Average Precision
API | Application Programming Interface
BCE | Binary Cross-Entropy
CIoU | Complete Intersection over Union (loss)
CNN | Convolutional Neural Network
COCO | Common Objects in Context (dataset)
CPU / GPU | Central / Graphics Processing Unit
CRUD | Create, Read, Update, Delete
DFL | Distribution Focal Loss
DRS | Deposit-Return Scheme
DTO | Data Transfer Object
EF Core | Entity Framework Core
FP / FN / TP | False Positive / False Negative / True Positive
FPS | Frames Per Second
HTTP(S) | Hypertext Transfer Protocol (Secure)
IoU | Intersection over Union
JWT | JSON Web Token
ML | Machine Learning
ONNX | Open Neural Network Exchange
OTP | One-Time Password (pairing code)
PET | Polyethylene Terephthalate
PWA | Progressive Web App
QR | Quick-Response (code)
REST | Representational State Transfer
RVM | Reverse-Vending Machine
SPA | Single-Page Application
UTC | Coordinated Universal Time
YOLO | You Only Look Once

### Chapter 1 Introduction

This chapter introduces the Keep It Green project. It presents the context and the problem the project addresses, the motivation behind it, the aim and objectives, the scope and deliverables, an overview of the proposed solution, the main contributions of the work, the development methodology followed by the team, and finally the organization of the remainder of this document.

### 1.1 Overview

Waste management is one of the defining challenges of modern cities, and beverage containers made of plastic and aluminium are among the most visible and voluminous components of everyday waste. Both materials are technically recyclable and, in the case of aluminium, almost infinitely so; yet the rate at which they are actually recovered remains low in the absence of a system that makes recycling both convenient and rewarding for the individual. Keep It Green is a graduation project that addresses this gap directly by building an intelligent reverse-vending machine that identifies recyclable items automatically, rewards the depositor for each accepted item, and sorts the item into the correct compartment.

Unlike a traditional bin, which is a passive receptacle, a reverse-vending machine (RVM) is an active device: it accepts a used container, verifies it, and gives the depositor something in return. Commercial reverse-vending machines already underpin the highly successful deposit-return schemes of northern Europe, where container-return rates routinely exceed ninety-five per cent. Those machines, however, rely on two enabling conditions that do not exist in the Egyptian market: national deposit legislation that attaches a refundable value to every container, and standardized barcodes printed on the containers that the machine scans to identify them. Keep It Green removes both dependencies. It uses computer vision to recognize the material of the item directly from a camera image, so it can operate in a market with no deposit law and on containers that may be crushed, unlabelled, or otherwise unfamiliar.

The system is not a single device but an integrated ecosystem of five cooperating components: an artificial-intelligence machine that performs the detection and sorting; a cloud backend that manages users, sessions, points, and rewards; a mobile application through which a user pairs with the machine and collects rewards; a web application that provides the same capabilities in a browser; and an on-machine kiosk interface designed to be understood at a glance. Together these components turn the simple act of returning a bottle or a can into an immediate, phone-based reward, and they do so through a single, secure, authenticated backend.

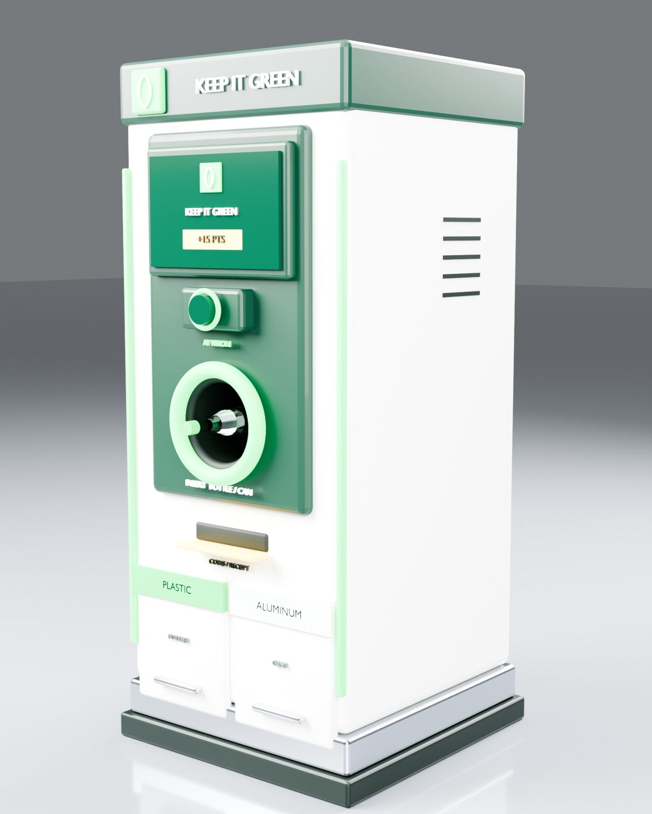
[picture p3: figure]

Figure 1.1: The Keep It Green reverse-vending machine (industrial-design render).

### 1.2 Problem Statement

The central problem this project addresses can be stated concisely: citizens have little practical incentive to recycle individual beverage containers, and the collection systems available to them are inconvenient, provide no immediate reward, and give no feedback on the impact of the individual's contribution. As a consequence, large quantities of valuable and fully recyclable material are lost to landfill and to the environment. This is a behavioural problem as much as a technical one — people are willing to recycle when it is easy and worthwhile, and they are unwilling when it is neither.

A second, more technical problem sits underneath the first. Automatically distinguishing recyclable materials at the point of disposal — reliably, in real time, at low cost, and without the barcodes that commercial machines depend upon — is a non-trivial engineering task. A workable solution must recognize the target materials accurately, reject everything that is not a target material, respond within a second so that the user is not kept waiting, and do all of this on affordable, commodity hardware. Solving both problems together — the behavioural and the technical — is the challenge that defines this project.

### 1.3 Motivation

Three observations motivate the project. The first is the scale of the problem, which is both global and local. Worldwide, consumers purchase close to one million plastic bottles every minute, and only a small fraction of all plastic ever produced has been recycled. In Egypt, the country generates on the order of one hundred million tonnes of solid waste annually and, while the national recycling rate has improved markedly in recent years, a large fraction of recyclable material is still not recovered.

The second observation is that the solution is already proven elsewhere. Reward-based reverse vending, operating under deposit-return legislation, achieves container-return rates above ninety-five per cent wherever it is deployed at scale. The missing ingredient in markets like Egypt is therefore not public awareness — surveys consistently show that people care about the environment — but a direct, tangible, convenient reward for the act of returning a container. Keep It Green supplies exactly that missing reward layer.

The third observation is that the conditions for a mobile-first reward system are unusually favourable in Egypt. The country has a population of well over one hundred million people, a low median age, and near-universal mobile-phone penetration. A system that delivers rewards to a smartphone, rather than dispensing cash or printing a coupon, aligns naturally with how the target population already lives and transacts, and it does so without the cost and mechanical complexity of a cash-handling machine.

### 1.4 Aim and Objectives

The aim of the project is to design, build, deploy, and validate a complete smart-recycling reward system that makes recycling convenient and rewarding, using artificial intelligence to identify recyclable materials without reliance on deposit legislation or barcodes. To achieve this aim, the following objectives were defined:

1. To design and build a working reverse-vending machine that recognizes plastic bottles and aluminium cans automatically using a camera and an object-detection model.

2. To train an object-detection model that meets a target accuracy of at least 0.90 mean Average Precision at an intersection-over-union threshold of 0.5, while running fast enough for real-time use (under one second per item).
3. To handle non-recyclable and unfamiliar items gracefully by rejecting them, without requiring a dedicated training class for every possible object.
4. To develop a secure, layered backend that manages user accounts, machines, recycling sessions, reward points, and reward redemptions, exposing its functionality through a documented web API.
5. To design a safe pairing and session model that correctly attributes each recycled item to the correct user, even when many people use the same machine.
6. To build a mobile application through which users register, pair with a machine, watch points accrue in real time, and redeem rewards, and a web application and on-machine kiosk offering the same capabilities.
7. To integrate a physical sorting mechanism driven by a microcontroller.
8. To deploy the complete system to a public host and validate it end-to-end with automated tests.

### 1.5 Scope and Deliverables

The project delivers a functional, end-to-end prototype rather than a mass-manufactured product. It covers two reward classes — plastic bottles and aluminium cans — which together represent the highest-value, most-frequently-discarded beverage containers. Items that are neither are rejected rather than sorted. The reward economy (points, vendors, and promotional codes) is fully implemented in software; the physical sorting mechanism is implemented at prototype scale using a microcontroller and servo motors. Large-scale manufacturing, financial-payment integration, and sorting of additional materials are treated as future work in Chapter 13. Table 1.1 lists the concrete deliverables of the project.

Table 1.1: Project deliverables.
# | Deliverable | Form

1 | Trained object-detection model (plastic + aluminium) | .pt and .onnx model files
2 | Machine control software (detection + sorting + session) | Python application
3 | Backend web API with database | ASP.NET Core service, deployed
4 | Mobile reward application | Installable Android package (APK)
5 | Web application and administrator dashboard | Progressive Web App
6 | On-machine kiosk interface | Web UI served by the backend

# | Deliverable | Form

7 | Hardware sorting prototype | Arduino + servos + enclosure
8 | Automated test suites | End-to-end test scripts

### 1.6 Overview of the Proposed Solution

The proposed solution links the five components through a single authenticated backend, following one strict design principle: no component ever touches the database directly. Every request — whether it originates from the machine, the phone, or a browser — passes through the backend web API and is authenticated before it can read or change any data. This concentrates all business rules and security in one place and makes the system safe to expose publicly. Figure 1.2 shows the high-level architecture; the components and their interactions are described in full in Chapter 4.

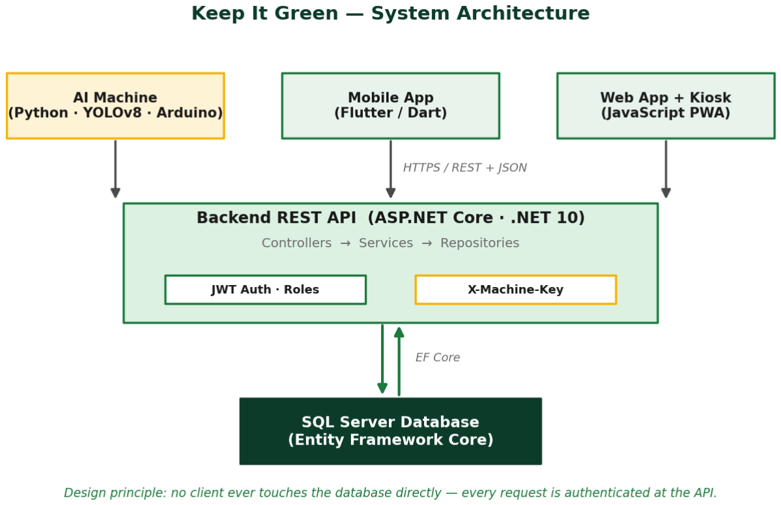
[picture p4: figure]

Figure 1.2: High-level system architecture of Keep It Green.
The user's experience is deliberately modelled on an automated teller machine. The machine displays a pairing code; the user pairs their phone to that code; the machine then attributes every item it detects to the paired user until the user finishes the session. This ATM-style model, detailed in Chapter 4, is what allows a single shared machine to serve many people safely and unambiguously.

### 1.7 Contributions

The main contributions of this work are the following:

- A complete, integrated, and publicly deployed reverse-vending system spanning artificial intelligence, cloud backend, mobile, web, and hardware — not a concept or a single module, but a working system that anyone can try.
- A material-recognition detector for plastic bottles and aluminium cans, trained on a unified dataset fused from four real-box detection sources, that exceeds the accuracy target while running in real time on commodity hardware.
- An open-set rejection scheme based on confidence thresholding, which allows the machine to reject non-recyclable items reliably without a dedicated “other” class that would otherwise dominate and bias training.
- An ATM-style pairing and session model that safely supports many simultaneous users on shared machines, verified by dedicated isolation testing.

### 1.8 Development Methodology

The project was developed using an iterative, incremental methodology inspired by Agile practice. Rather than attempting to specify and build the entire system in a single pass, the team worked in short cycles, each of which produced a working increment of the system that could be demonstrated and tested. Early cycles established the backend data model and the core recycling flow; later cycles added the artificial-intelligence detector, the mobile and web frontends, the hardware integration, and finally public deployment and hardening. This approach allowed design decisions to be validated against a running system continuously, and it made it possible to detect and correct integration problems early, when they were cheap to fix. Version control, a shared backend, and automated end-to-end tests supported the parallel work of the team members, whose responsibilities spanned artificial intelligence and hardware, mobile development, front-end development, and back-end development.

### 1.9 Organization of the Book

The remainder of this document is organized as follows. Chapter 2 reviews the relevant background and related work, covering the waste problem, deposit-return schemes, reverse-vending machines, computer vision for waste sorting, and the object-detection techniques used. Chapter 3 presents the requirements engineering and analysis, including functional and non-functional requirements, use-case models, and feasibility and risk analyses. Chapter 4 describes the overall system architecture and design, including the database schema, the API, the security design, and the session model. Chapter 5 details the artificial-intelligence module in depth. Chapters 6, 7, 8, and 9 cover the backend, the mobile application, the web and kiosk interfaces, and the hardware respectively. Chapter 10 presents the testing and validation strategy and its results. Chapter 11 covers deployment and operations. Chapter 12 discusses the results, and Chapter 13 concludes and outlines directions for future work. A set of appendices provides the full API reference, key code listings, the database schema, an installation and user manual, the complete test-case catalogue, and the hardware bill of materials.

### 1.10 The Team and Its Responsibilities

The project was carried out by a team of six students whose responsibilities were divided along the natural seams of the system, so that each major component had a clear owner while the interfaces between components were agreed and tested jointly. Table 1.2 records the division of responsibilities. The artificial-intelligence and hardware work — data, model, machine software, and the Arduino — formed the largest effort and was shared among three members; the mobile, front-end, and back-end responsibilities were each led by a dedicated member. Integration, testing, and deployment were shared across the team, reflecting the principle that the value of the project lies in the working whole.

Table 1.2: Team members and primary responsibilities.
Member | Primary responsibility
Yousef Badr | Team lead · AI and hardware · machine integration
Eslam Medhat | Artificial intelligence · dataset and model
Ahmed Anwer | Artificial intelligence · training and evaluation
Mohanad Ayman | Mobile application (Flutter)
Menna Osama | Front-end / web application
Shahd El Aswad | Back-end / API and database

### 1.11 Significance of the Project

The significance of Keep It Green lies in the way it combines a social objective with a technical one. Socially, it addresses a real and pressing problem — the low recovery of recyclable containers in a country actively seeking to raise its recycling rate — with an approach that is proven to change behaviour, namely an immediate reward for the individual. Technically, it demonstrates that this reward layer can be delivered without the deposit legislation and barcode infrastructure that formal schemes depend upon, by substituting affordable artificial intelligence for that infrastructure. The project therefore matters not only as an academic exercise but as a demonstration of a deployable model for improving recycling in emerging markets.

For the students who built it, the project is also significant as a complete engineering experience. It required specifying, designing, implementing, integrating, testing, and deploying a system that spans machine learning, cloud services, mobile and web development, and embedded hardware — the full breadth of a modern software system — and doing so as a coordinated team. The result is evidence that the team can carry an ambitious idea all the way from concept to a working, deployed, and validated product.
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

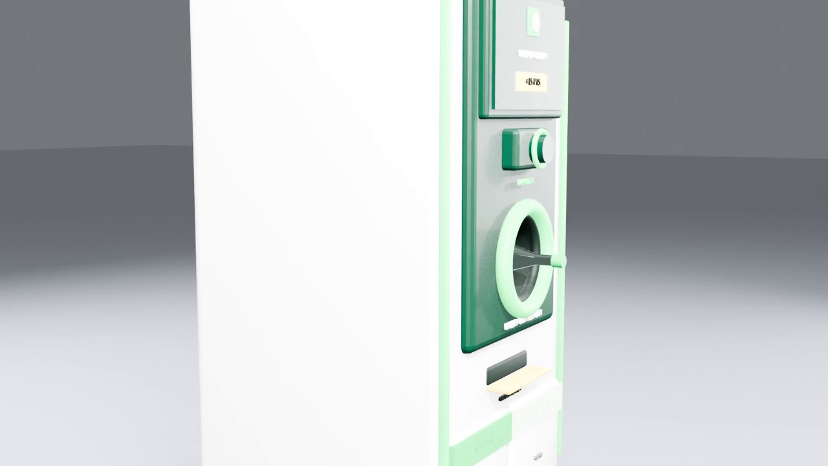
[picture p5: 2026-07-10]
Presentation/assets/tour_poster.png

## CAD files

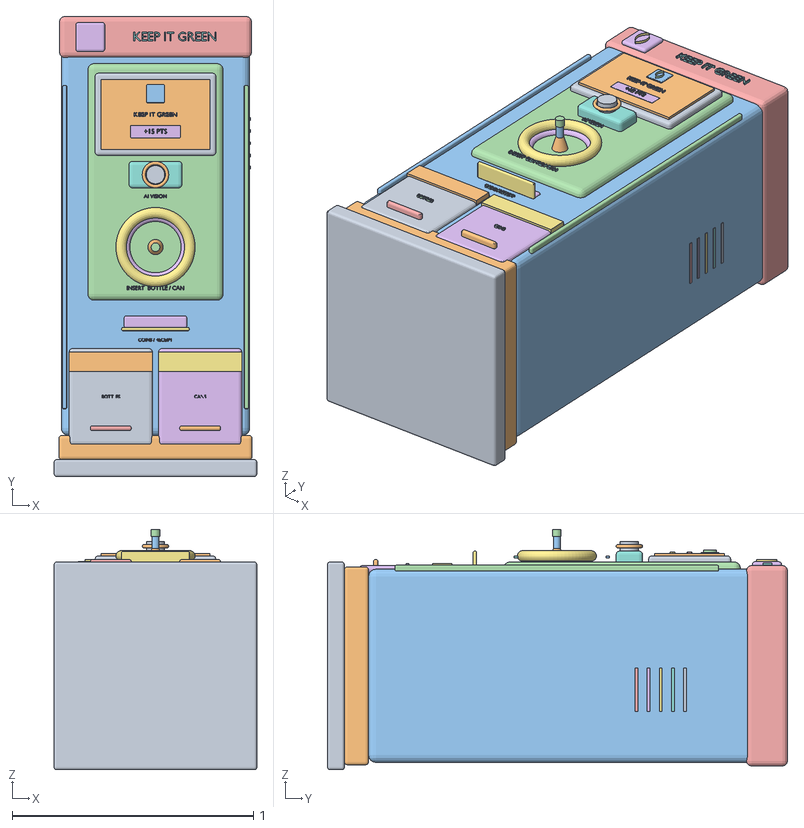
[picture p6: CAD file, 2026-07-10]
Design/keep_it_green_machine.obj
0.84 x 1.91 x 0.995
plinth
base
cabinet
control_panel
crown
logo_token
logo_leaf
Text
screen_bezel
screen
ui_token
ui_leaf
Text.001
ui_pill
Text.002
cam_housing
cam_lens
cam_ring
Text.003
intake_liner
intake_back
intake_gasket
intake_ring
Text.004
bottle_body
bottle_shoulder
bottle_neck
bottle_cap
bottle_label
tray_slot
tray_lip
Text.005
door_PLASTIC
stripe_PLASTIC
Text.006
Text.007
handle_PLASTIC
door_ALUMINUM
stripe_ALUMINUM
Text.008
Text.009
handle_ALUMINUM
led_-1
led_1
vent_0
vent_1
vent_2
vent_3
vent_4

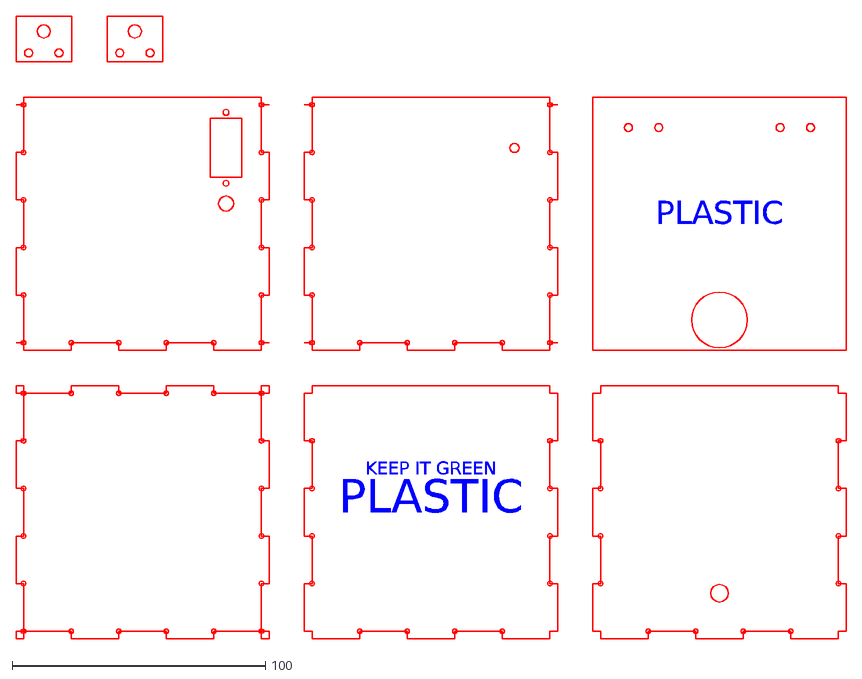
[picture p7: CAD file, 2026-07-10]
Prototype_Boxes/out/keepitgreen_cube_PLASTIC.dxf
PLASTIC
KEEP IT GREEN

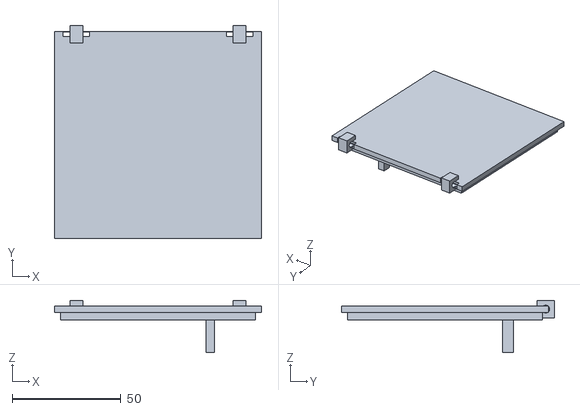
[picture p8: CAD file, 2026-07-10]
Prototype_Boxes/out/bin_lid.stl
95.0 x 97.8 x 24.0

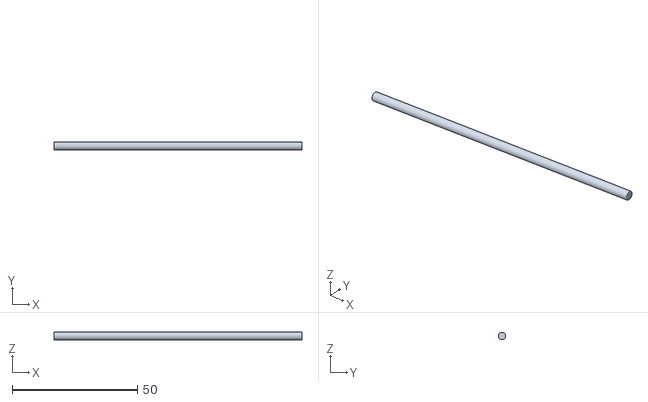
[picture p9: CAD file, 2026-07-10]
Prototype_Boxes/out/bin_hinge_pin.stl
99.0 x 3.00 x 3.00

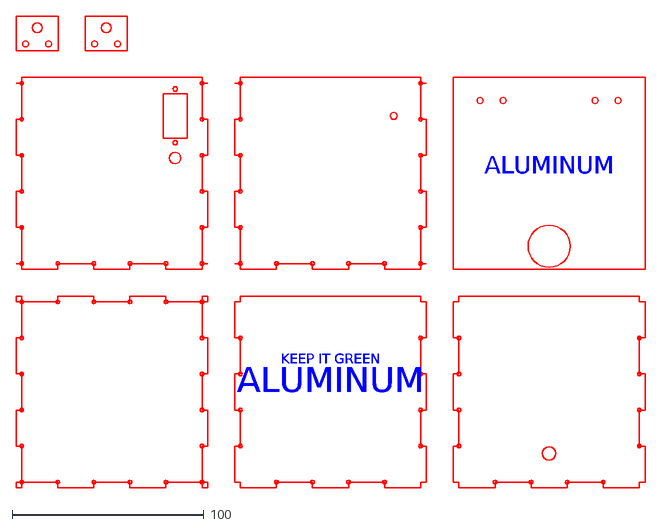
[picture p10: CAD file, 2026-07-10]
Prototype_Boxes/out/keepitgreen_cube_ALUMINUM.dxf
ALUMINUM
KEEP IT GREEN

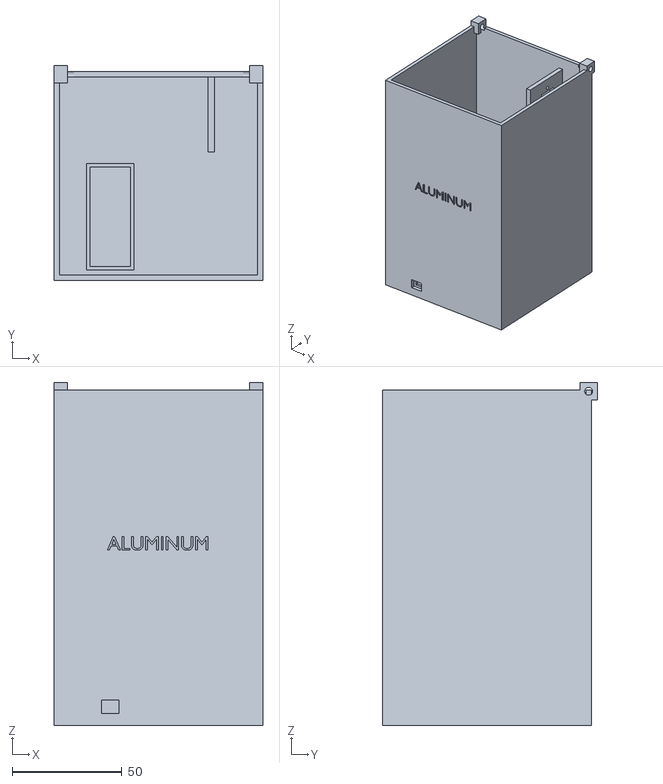
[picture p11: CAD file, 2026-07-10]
Prototype_Boxes/out/bin_body_ALUMINUM.stl
95.0 x 97.8 x 156.0

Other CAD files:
Prototype_Boxes/out/bin_body_PLASTIC.stl
Design/keep_it_green_machine.blend
Prototype_Boxes/keep_it_green_bins.blend

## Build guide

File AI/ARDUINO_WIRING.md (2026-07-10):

# Keep It Green — Arduino Wiring & Test Guide

Hardware you are using: **Arduino Nano** + **2× SG90 micro-servos** (plastic gate + aluminium gate).

---

## 1. Wiring

Each SG90 has 3 wires: **orange/yellow = signal**, **red = +5 V**, **brown/black = GND**.

| From (Arduino Nano) | To | Notes |
|---|---|---|
| **D9** | Plastic servo **signal** (orange) | PWM pin |
| **D10** | Aluminium servo **signal** (orange) | PWM pin |
| **5V** | Both servos **+5V** (red) | ⚠️ see Power note |
| **GND** | Both servos **GND** (brown) | must be common ground |
| **D7** → 220 Ω → LED → GND | Green LED (optional) | on while a gate is open |
| **D6** → 220 Ω → LED → GND | Red LED (optional) | blinks on a rejected item |

```
   Arduino Nano                       SG90 (plastic)
   ┌──────────┐        orange  ┌──────────────┐
   │       D9 ├────────────────┤ signal        │
   │       D10├──────┐         │ +5V ─── red   │
   │       5V ├──────┼────┬────┤ GND ─── brown │
   │      GND ├──────┼────┼─┐  └──────────────┘
   │       D7 ├─[220Ω]─▶│ │ │      SG90 (aluminium)
   │       D6 ├─[220Ω]─▶│ │ │  ┌──────────────┐
   └──────────┘   green red│ └──┤ signal (D10)  │
                    LEDs    └────┤ +5V / GND     │
                                 └──────────────┘
```

### ⚠️ Power note (read this)
One SG90 draws ~100–250 mA, and **>400 mA at stall**. Two of them can exceed what the
Nano's USB/5V pin can supply and cause **brown-outs / random resets**.

- **Bench test (one servo, short moves):** powering from the Nano **5V** pin is usually fine.
- **Real machine (both servos):** power the servos from a **separate 5 V supply** (5 V/2 A
  adapter or a UBEC). **Join the grounds** — servo GND must connect to **both** the external
  supply GND **and** the Nano GND (common ground). Signal wires still go to D9/D10.

---

## 2. Flash the sketch

1. Open **`recycling_machine.ino`** in the Arduino IDE. (If the IDE asks to move it into a
   folder named `recycling_machine`, say yes.)
2. **Tools → Board → Arduino Nano.**
3. **Tools → Processor →** `ATmega328P` — if upload fails, try **`ATmega328P (Old Bootloader)`**
   (most clone Nanos need this).
4. **Tools → Port →** your Nano's port (e.g. `COM5`). If no port appears, install the
   **CH340** USB driver (most clone Nanos) or the FTDI driver.
5. Click **Upload**.

On power-up the sketch runs a **self-test**: both gates open and close once. If they move,
your wiring is correct — you can verify this **with no laptop program running**.

---

## 3. Test it (before the full machine)

Use the bench tester — it talks to the Arduino directly, no camera/model needed:

```bash
pip install pyserial
python arduino_test.py --list     # find your port, e.g. COM5
python arduino_test.py COM5       # open it
```

Then type:
- `P` → plastic gate opens ~3 s and closes
- `A` → aluminium gate opens and closes
- `T` → self-test both gates
- `auto` → fires P, A, P, A automatically
- `q` → quit

You should see replies like `READY`, `ACK:P`, `DONE:P`.

---

## 4. Connect it to the real machine

When the bench test works, plug the Nano into the machine laptop and tell `machine.py`
which port to use. In **`machine.py`** (top of the file) change **one line**:

```python
ARDUINO_PORT = None        # <-- change to your port, e.g. "COM5"  (Linux: "/dev/ttyUSB0")
```

That's the only change needed — `machine.py` already sends `P`/`A` on each accepted item,
which matches the sketch. Baud is 9600 on both sides.

- Leave `ARDUINO_PORT = None` and the machine runs fine **without** the Arduino (no sorting).
- Set it to your port and the servos actuate on every accepted item.
- Tip: run `machine.py` — even in **SIMULATE mode** (no camera/model) it auto-generates items,
  so you can watch the servos fire end-to-end.

---

## 5. Things you may want to adjust (all at the top of `recycling_machine.ino`)

| Setting | Default | Change if… |
|---|---|---|
| `SERVO_PLASTIC_PIN` / `SERVO_ALUMINUM_PIN` | 9 / 10 | you wired the signal to different pins |
| `OPEN_ANGLE` / `CLOSE_ANGLE` | 90 / 0 | the gate opens the wrong way or not far enough |
| `OPEN_MS` | 3000 ms | the item needs more/less time to drop through |
| `BOOT_SELFTEST` | true | set `false` once installed, to skip the power-up sweep |
| `LED_GREEN_PIN` / `LED_RED_PIN` | 7 / 6 | you don't use the LEDs, or wired them elsewhere |

**Serial commands the board understands:** `P` (plastic), `A` (aluminium), `O` (reject blink),
`T` (self-test). Replies: `READY`, `ACK:x`, `DONE:x`, `REJECT`, `TEST:…`, `SELFTEST:DONE`.

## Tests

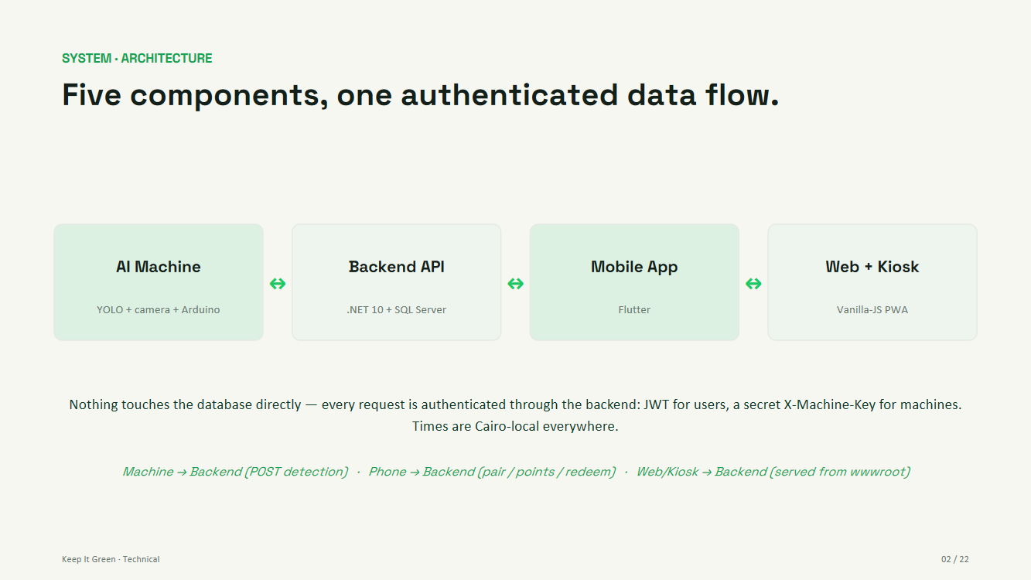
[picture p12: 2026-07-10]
Presentation/qa_tech/t-02.png

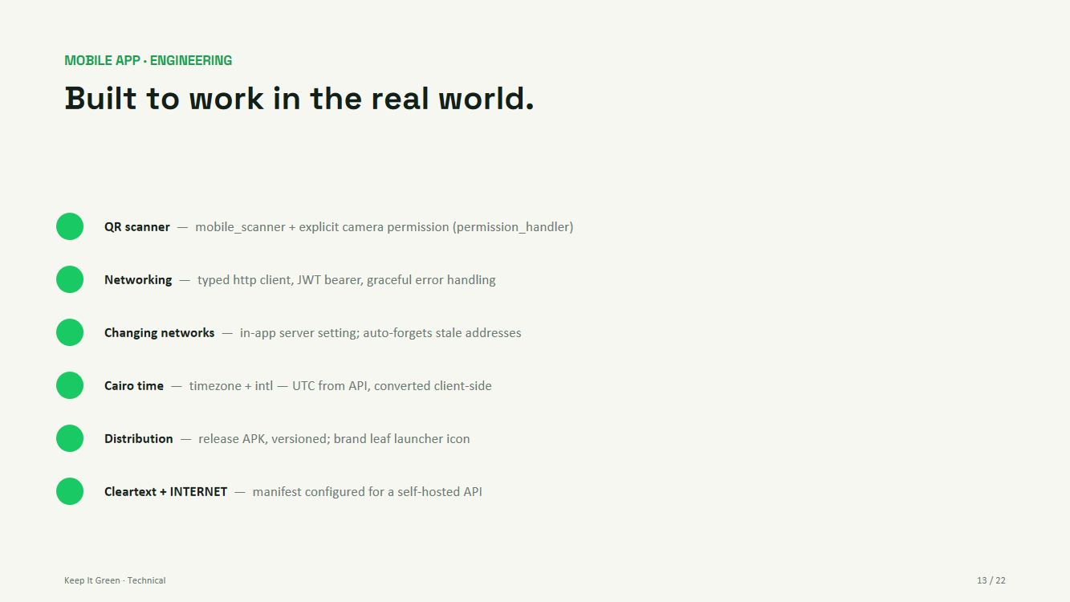
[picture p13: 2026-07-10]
Presentation/qa_tech/t-13.png

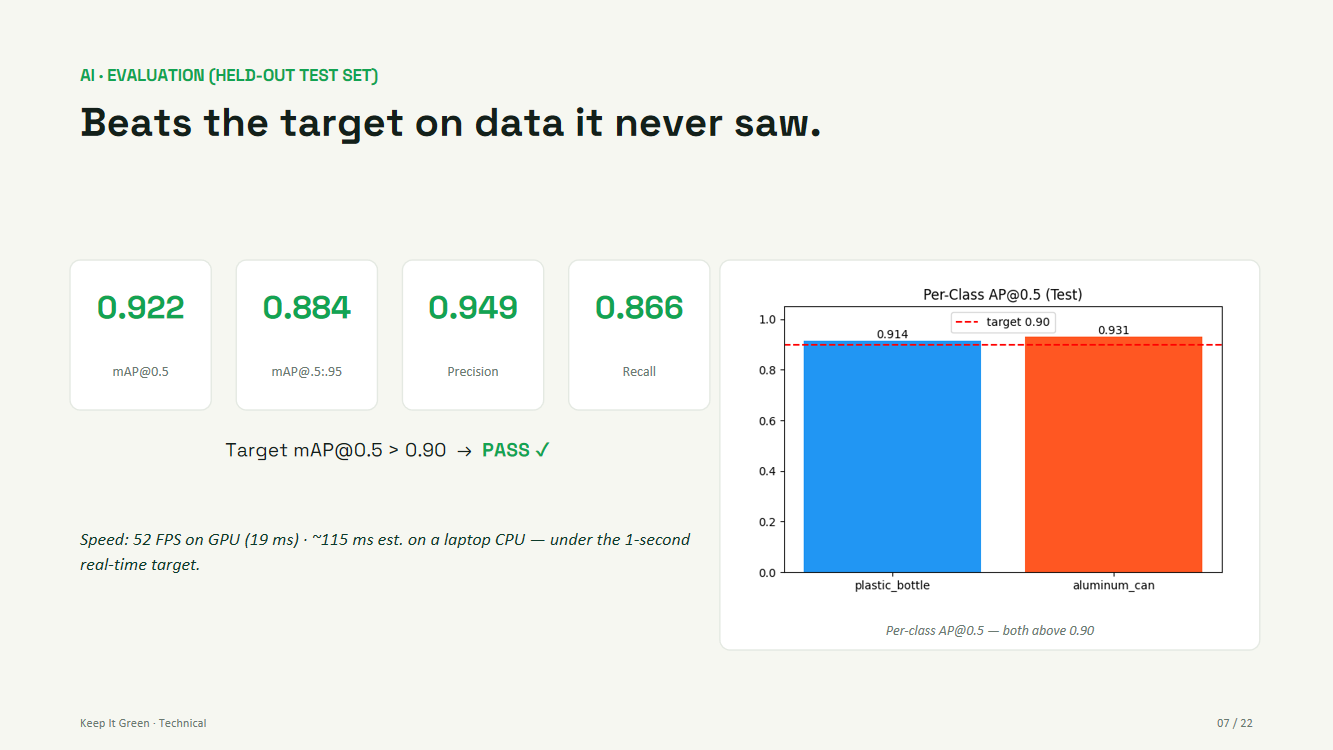
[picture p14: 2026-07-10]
Presentation/qa_tech/t-07.png

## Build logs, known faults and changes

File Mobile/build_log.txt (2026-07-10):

Running Gradle task 'assembleRelease'...                        
Font asset "MaterialIcons-Regular.otf" was tree-shaken, reducing it from 1645184 to 6408 bytes (99.6% reduction). Tree-shaking can be disabled by providing the --no-tree-shake-icons flag when building your app.
Running Gradle task 'assembleRelease'...                          197.4s
√ Built build\app\outputs\flutter-apk\app-release.apk (58.8MB)

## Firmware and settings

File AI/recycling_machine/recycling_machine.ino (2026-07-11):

/*
  Keep It Green — Arduino Compartment Controller  (Arduino NANO + 2× SG90)
  ========================================================================
  Receives one-byte commands from the laptop (machine.py) over USB serial and
  opens the matching compartment with an SG90 micro-servo:

      'P' -> Plastic compartment   (Servo 1, pin D9)
      'A' -> Aluminum compartment  (Servo 2, pin D10)
      'O' -> Rejected item         (red LED blink, no compartment)   [optional]
      'T' -> Self-test both gates  (use the serial tester to verify wiring)

  ---------------------------------------------------------------------------
  WIRING  (Arduino Nano)                     SG90 servo leads
  ---------------------------------------------------------------------------
    Plastic servo  signal (orange) -> D9        orange/yellow = SIGNAL
    Aluminum servo signal (orange) -> D10       red           = +5V
    Green LED (+ 220R) ------------ -> D7        brown/black   = GND
    Red   LED (+ 220R) ------------ -> D6
    Both servos  +5V (red) -------- -> 5V *          * SEE POWER NOTE
    Both servos  GND (brown) ------ -> GND
    LED cathodes ------------------ -> GND

  POWER NOTE (important for 2× SG90):
    One SG90 can draw ~100-250 mA, and >400 mA at stall. Two of them may exceed
    what the Nano's onboard 5V/USB can supply, causing brown-outs / random resets.
    For reliable operation power the servos from a SEPARATE 5V supply (e.g. a
    5V 2A adapter or a UBEC) and join the grounds:  servo +5V -> external 5V,
    servo GND -> external GND AND Nano GND (COMMON GROUND is required).
    For a quick bench test one servo at a time off the Nano 5V is usually fine.

  Design notes:
    - NON-BLOCKING: a millis() state machine runs the open/close cycle so the
      board keeps reading serial and never misses a command (no delay() stalls).
    - Servos DETACH after closing to stop holding-torque jitter/buzzing/heat.
    - On boot it runs a SELF-TEST (both gates open+close) so you can confirm the
      wiring works with NO laptop connected.  Set BOOT_SELFTEST=false to skip.
    - Sends ACKs back to the laptop: "READY", "ACK:P", "DONE:P", "REJECT".
    - Baud 9600 — must match machine.py BAUD_RATE.
*/

#include <Servo.h>

// ─── Pin config  (change here if you wire to different pins) ──────────────────
const int SERVO_PLASTIC_PIN  = 9;
const int SERVO_ALUMINUM_PIN = 10;
const int LED_GREEN_PIN      = 7;   // lights while a compartment is open (optional)
const int LED_RED_PIN        = 6;   // blinks on a rejected item          (optional)

// ─── Servo angles / timing  (tune for your gate mechanism) ───────────────────
const int           CLOSE_ANGLE = 90;      // gate shut
const int           OPEN_ANGLE  = 180;     // gate open (SG90 range is 0..180)
const unsigned long OPEN_MS     = 5000;   // how long the compartment stays open
const unsigned long REJECT_MS   = 500;    // red LED blink duration
const bool          BOOT_SELFTEST = true; // sweep both gates once on power-up

Servo servoPlastic;
Servo servoAluminum;

// ─── Non-blocking state machine ───────────────────────────────────────────────
enum State { IDLE, OPENING, REJECTING };
State         state       = IDLE;
unsigned long stateStart  = 0;
Servo*        activeServo = nullptr;
char          activeCmd   = 0;


// Blocking open+close of one gate — used only by the self-test / 'T' command.
void testGate(Servo &servo, int pin, const char *name) {
  Serial.print("TEST:"); Serial.println(name);
  servo.attach(pin);
  servo.write(OPEN_ANGLE);  delay(700);
  servo.write(CLOSE_ANGLE); delay(700);
  servo.detach();
}

void selfTest() {
  digitalWrite(LED_GREEN_PIN, HIGH);
  testGate(servoPlastic,  SERVO_PLASTIC_PIN,  "PLASTIC");
  testGate(servoAluminum, SERVO_ALUMINUM_PIN, "ALUMINUM");
  digitalWrite(LED_GREEN_PIN, LOW);
  Serial.println("SELFTEST:DONE");
}


void setup() {
  Serial.begin(9600);
  pinMode(LED_GREEN_PIN, OUTPUT);
  pinMode(LED_RED_PIN,   OUTPUT);

  // Set both gates to the closed position, then detach to stop jitter.
  servoPlastic.attach(SERVO_PLASTIC_PIN);
  servoAluminum.attach(SERVO_ALUMINUM_PIN);
  servoPlastic.write(CLOSE_ANGLE);
  servoAluminum.write(CLOSE_ANGLE);
  delay(500);
  servoPlastic.detach();
  servoAluminum.detach();

  if (BOOT_SELFTEST) selfTest();   // move both gates so you can verify wiring
  Serial.println("READY");
}


// Begin opening a compartment (returns immediately — non-blocking).
void beginOpen(Servo &servo, int pin, char cmd) {
  activeServo = &servo;
  activeCmd   = cmd;
  servo.attach(pin);
  servo.write(OPEN_ANGLE);
  digitalWrite(LED_GREEN_PIN, HIGH);
  state      = OPENING;
  stateStart = millis();
  Serial.print("ACK:"); Serial.println(cmd);
}

void beginReject() {
  digitalWrite(LED_RED_PIN, HIGH);
  state      = REJECTING;
  stateStart = millis();
  Serial.println("REJECT");
}

void handleSerial() {
  if (Serial.available() <= 0) return;
  char cmd = (char)Serial.read();

  if (cmd == 'T') { selfTest(); return; }   // manual test (allowed any time)
  if (state != IDLE) return;                // ignore P/A/O mid-cycle

  if      (cmd == 'P') beginOpen(servoPlastic,  SERVO_PLASTIC_PIN,  'P');
  else if (cmd == 'A') beginOpen(servoAluminum, SERVO_ALUMINUM_PIN, 'A');
  else if (cmd == 'O') beginReject();
}

void updateState() {
  unsigned long now = millis();
  if (state == OPENING && now - stateStart >= OPEN_MS) {
    activeServo->write(CLOSE_ANGLE);
    delay(300);                 // brief settle before detaching
    activeServo->detach();      // stop holding torque -> no jitter
    digitalWrite(LED_GREEN_PIN, LOW);
    Serial.print("DONE:"); Serial.println(activeCmd);
    state = IDLE;
    activeServo = nullptr;
  }
  else if (state == REJECTING && now - stateStart >= REJECT_MS) {
    digitalWrite(LED_RED_PIN, LOW);
    state = IDLE;
  }
}

void loop() {
  handleSerial();   // read commands (never blocked)
  updateState();    // advance the open/close cycle
}

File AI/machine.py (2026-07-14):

"""
Keep It Green — Machine (single program, ATM kiosk on the laptop)
=================================================================
ONE program that runs on the recycling-machine laptop. It:
  - shows the ATM kiosk UI full-screen (the official design) in a built-in window,
  - runs the YOLO model + webcam + Arduino IN THIS SAME PYTHON PROCESS,
  - starts an ATM session on the backend  ->  shows a QR + 6-digit code,
  - the user SCANS the QR with the app, OR types a code from the app on the keypad,
  - on each accepted item: posts the transaction, opens the servo, animates the screen.

No separate "bridge" / web server — the UI is embedded and driven directly from Python.

Run:   python machine.py
Deps:  pip install pywebview ultralytics opencv-python pyserial requests "qrcode[pil]"
       (If ultralytics/opencv are missing it runs in SIMULATE mode so you can still demo.)
Needs: the backend running (it serves the kiosk page) and keep_it_green_best.pt next to this file.
"""

import base64
import io
import json
import threading
import time
from pathlib import Path

import requests

try:
    import webview
except Exception:
    webview = None

try:
    import cv2
    from ultralytics import YOLO
    HAS_CV = True
except Exception:
    HAS_CV = False
try:
    import serial
    HAS_SERIAL = True
except Exception:
    HAS_SERIAL = False
try:
    import qrcode
    HAS_QR = True
except Exception:
    HAS_QR = False

# ----------------------------- Configuration -----------------------------
# Secrets/deploy values live in machine_config.json NEXT TO THIS FILE (kept out of
# version control), overridable by environment variables. Nothing secret is in code.
#   machine_config.json: { "backend_base": "...", "machine_key": "...", "machine_id": 2, ... }
import os as _os

def _load_cfg():
    cfg = {}
    p = Path(__file__).resolve().parent / "machine_config.json"
    if p.exists():
        try:
            cfg = json.loads(p.read_text(encoding="utf-8"))
        except Exception as e:
            print("[WARN] machine_config.json is invalid:", e)
    return cfg

_cfg = _load_cfg()
BACKEND_BASE = _os.environ.get("KIG_BACKEND", _cfg.get("backend_base", "http://localhost:5217"))
KIOSK_URL    = BACKEND_BASE + "/kiosk/"
MACHINE_KEY  = _os.environ.get("KIG_MACHINE_KEY", _cfg.get("machine_key", ""))
MACHINE_ID   = int(_os.environ.get("KIG_MACHINE_ID", _cfg.get("machine_id", 1)))
LOCATION     = _cfg.get("location", "Cairo")     # fallback; the backend supplies the real one
if not MACHINE_KEY:
    print("[ERROR] No machine key configured. Create AI/machine_config.json with")
    print('        {"backend_base": "https://...", "machine_key": "...", "machine_id": 2}')
    print("        or set the KIG_MACHINE_KEY environment variable.")

MODEL_PATH   = str(Path(__file__).resolve().parent / "keep_it_green_best_V4.pt")
CONF_THRESH  = 0.65

# ── Detection sanity guards + diagnostics ────────────────────────────────────
# Points are awarded from the detected CLASS (plastic/aluminium); the box is only
# used for the on-screen frame. If the model returns a box that fills (almost) the
# whole frame it has NOT localised the object — a known weakness of this model on
# the machine's webcam (full-frame training labels + domain gap; see NOTES below).
# We ALWAYS log that so a fault is never silent, and can optionally reject it.
MIN_BOX_AREA_FRAC  = 0.01   # a real box shouldn't be a tiny speck ...
MAX_BOX_AREA_FRAC  = 0.95   # ... nor fill ≥95% of the frame (that = a full-frame hallucination).
                            # Tuned for the retrained tight-box model: real close-up items may be
                            # large but a genuine detection won't fill the whole frame. Old model
                            # emitted 100%-area boxes, which this still rejects.
REJECT_UNLOCALIZED = True   # STRICT (default): drop non-localised (full-frame) reads so
                            # the machine does NOT hallucinate an item on an empty intake.
                            # With the current model this also rejects most REAL items
                            # (their boxes come back full-frame too) — that is the signal
                            # to retrain. Set False to count anyway (logs "[!]" per read).
DEBUG_DETECT       = True   # print each frame's top raw model output to the terminal
#
# NOTES — if detection misbehaves, it is the MODEL, not this file:
#   * Proof: run  python test_webcam.py  and watch the "area=" column. ~100% on a
#     real item (or a plastic read on an empty intake) = the model, full stop.
#   * Root cause: ~74% of training boxes were full-frame (classification datasets
#     converted to whole-image boxes) + a plastic/aluminium class imbalance, so the
#     model classifies well but localises poorly and over-predicts "plastic".
#   * Real fix: retrain with TIGHT boxes, add real machine-camera images (the
#     AI/captures/ frames are perfect labelling material) and some empty-intake
#     "background" images, and rebalance the two classes. Then boxes come out tight
#     and this guard can be switched to strict (REJECT_UNLOCALIZED = True).

STABLE_SECONDS = 1.2       # an item must stay detected this long before it counts (anti-misfire buffer)
FLICKER_GAP    = 0.4       # tolerate a dropout this long without resetting the buffer (jittery model)
COOLDOWN_SEC = 3
SESSION_IDLE_TIMEOUT = 60        # end the session after this many seconds with no item

ARDUINO_PORT = _cfg.get("arduino_port", None)   # e.g. "COM5" in machine_config.json; null disables servos
BAUD_RATE    = 9600

POINTS  = {"Plastic": 10, "Aluminum": 15}
DISPLAY = {"Plastic": "Plastic bottle", "Aluminum": "Aluminum can"}
SERIAL_CMD = {"Plastic": b"P", "Aluminum": b"A"}

SIMULATE = not HAS_CV            # no model/camera -> simulate items for the demo

# ----------------------------- shared state ------------------------------
_lock = threading.Lock()
_det = {"item": None, "conf": 0.0, "frame": None}
_entered = {"code": None}        # a code typed on the kiosk keypad
_choice = {"v": None}            # "another" / "finish" tapped on the choice screen
_ui_state = {"s": "idle"}        # the screen currently shown
_session = {"active": False}     # True only while a user session is live (gates camera+model)
window = None


class Api:
    """Exposed to the kiosk page as window.pywebview.api"""
    def submit_code(self, code):
        code = (str(code) if code is not None else "").strip()
        if code:
            with _lock:
                _entered["code"] = code
        return True

    def choose(self, what):
        with _lock:
            _choice["v"] = what
        return True


def ui(state):
    _ui_state["s"] = state.get("state", _ui_state["s"])
    try:
        window.evaluate_js("kioskApply(" + json.dumps(state) + ")")
    except Exception:
        pass
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

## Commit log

2026-07-10 Initial commit: Keep It Green — AI recycling reward system
    Mobile (Flutter), machine (Python + YOLOv8 + Arduino), tests, book,
    presentations, database assets, and project docs. Backend lives in its
    own repo under Recycle/ (see README).
    [bin_body_ALUMINUM.stl, bin_body_PLASTIC.stl, bin_hinge_pin.stl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]
2026-07-11 Machine reliability: offline transaction queue, crash-proof detection, capture pruning
    - submit() retries 3x then queues to pending_transactions.jsonl; flushed at
    each session start — user points are never silently lost to a network blip
    - detection_supervisor restarts the detection loop if it ever crashes
    - captures/ auto-pruned to the newest 300 frames; camera_index configurable
    [machine.py]
2026-07-11 Release signing config, refresh-token client, captures labelling kit
    - Mobile: android release signingConfig reading android/key.properties
    (keystore + properties gitignored); silent token refresh + retry on 401;
    admin transactions request paged (200); v1.0.9+10
    - AI: prepare_captures.py packs machine-camera frames for Roboflow labelling
    (the path to fine-tuning the model on the real camera domain)
2026-07-11 Mobile: shared FilterSortBar on every long list
    FilterSortBar moved to widgets.dart; wired into Activity/history
    (type filter + date/points sort), Rewards (affordable filter +
    cost/vendor sort), admin vendors (sort); admin machines/reports
    switched to the shared widget. v1.0.10+11
2026-07-11 Arduino: tune gate angles + fix stray leading char
    Fix a stray 'a' at the top of the sketch; set CLOSE_ANGLE=90 / OPEN_ANGLE=180
    and OPEN_MS=5000 to match the real gate mechanism.
    [recycling_machine.ino]
2026-07-11 Arduino: auto-detect COM port + loud diagnostics so the gate actually fires
    The gate 'doing nothing' was a silent-failure chain: open_arduino() returned
    None with no message when the COM port was wrong (Windows renumbers COM ports
    on replug) or pyserial was missing, and the servo write was wrapped in a bare
    except: pass.
    - open_arduino(): try configured port, then AUTO-DETECT by scanning all serial
    ports (Arduino/CH340/CP210x first); wait for the board's READY line; log loudly
    - fire_gate(): write + flush + read back the ACK/DONE reply; real error logging
    - open the gate BEFORE submit() so a slow/failed network never delays the servo
    - arduino_test.py: same auto-detect when no port is giv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
    [arduino_test.py, machine.py]
2026-07-11 Arduino: open the gate in sync with the item-type screen
    The gate was opening a beat early (during the live green-box preview) because
    fire_gate ran before the blocking submit() and the 'detected' screen came after
    it. Now the item-type screen and the servo fire together (both local + instant),
    and submit() runs in a background thread so a slow network can't desync them.
2026-07-11 Deck: name the 4 fused datasets explicitly on the AI dataset slide
    Slide 4 said 'Four real-box detection datasets' without naming them. Add a
    line listing the actual fused sources (Drinking Waste, Beverage Containers,
    YOLO Waste Detection, Can-Bottle-Pack) with a note that TACO was evaluated
    but excluded (no verified box labels). Verified against today's notebook:
    same 4 datasets, unchanged numbers (mAP 0.928).
2026-07-12 Deck slide 3: replace stale class table with real V4 dataset sources
    Slide 3 (AI framing) still showed the pre-V4 classification numbers
    (Other ~44k / Plastic ~4k / Aluminum ~1k) which contradicted the V4
    notebook and slide 4 (balanced 8,534 / 8,238). Replace it with the actual
    4 fused real-box datasets (Drinking Waste 2,259, Beverage Containers 3,358,
    YOLO Waste Detection 4,563, Can-Bottle-Pack 1,717 -> 11,897 imgs), keep the
    open-set-rejection panel, and remove the now-redundant dataset line on s4.
2026-07-14 Fix redeem crash + Arduino wrong-port trap
    Backend: redeem ran a manual transaction under EnableRetryOnFailure, which threw
    'execution strategy does not support user-initiated transactions' on every redeem.
    TryRedeem now runs inside CreateExecutionStrategy().Execute with a raw-SQL insert
    (retry-safe). Verified e2e 26/26.
    Machine: open_arduino() now prefers the port that sends our sketch's READY
    handshake. Before, if the configured COM port was reassigned and a different
    device sat on it, we'd silently write to the wrong port and the gate never moved.
    [machine.py]
2026-07-14 Add combined graduation defense deck (36 slides)
    Keep_It_Green_Defense.pptx merges the best of all three decks via PowerPoint
    InsertFromFile: pitch + 3D machine model + machine video (from the pitch deck),
    the full latest technical deep-dive incl. V4 AI data & live deployment (from the
    technical deck), and the business/market section. Footers + page numbers unified
    to NN/36, 'Keep It Green' brand footer throughout, fade transitions on all slides,
    3D turntable animation preserved on the cover. Fonts embedded; opens clean.
2026-07-14 Align defense deck with the rehearsed narrative (36 slides)
    Restructured Keep_It_Green_Defense.pptx to the flow the team practiced:
    cover (practiced title + 'Supervised by Dr. Maha Tolba - 2025-2026' + practiced
    name spellings) -> Contents -> Introduction x2 (with Canva photos) -> Problem ->
    Insight -> Solution -> Product -> Architecture -> Mobile -> AI (new V4 data) ->
    Hardware -> Backend -> Web -> Kiosk -> Quality -> Deployment -> Business model
    (ERP B2B, practiced content) -> Future work -> Impact -> Team -> Q&A -> Close.
    Dropped the 6 unrehearsed investor slides. New slides themed to match (paper bg,
    Space Grotesk, mint cards). Two-phase rebuild avoids python-pptx duplicate-part
    corrupti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
